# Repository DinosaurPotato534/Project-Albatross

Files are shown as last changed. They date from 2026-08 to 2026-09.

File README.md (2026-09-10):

# Project Albatross

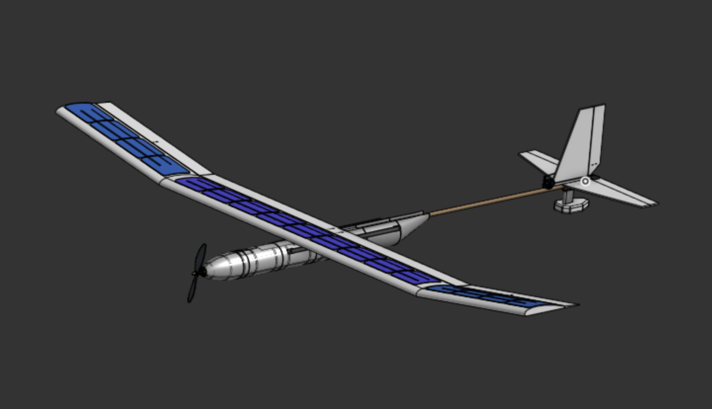
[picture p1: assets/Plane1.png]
plane


The goal for the project was to create an autonomous plane capable of flying for hours off of solar power. Another big aspect is the ability to takeoff from water using a pontoon system mounted to a 4-bar linkage. The plane is going to be made from foam board and 3d prints. The wingspan is 90in and the length is roughly 6ft. 

https://cad.onshape.com/documents/cb4d8119196719dc9005cd1f/w/a50220c0795171ae93763f3d/e/ee41d6fe8c21d3f854f1676d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

## Motivation
We wanted to explore the idea of multi-hour flight using solar power. Most rc planes have a relatively short flight time, but we wanted to try and expand on that. That is why we also added the pontoons, so it could recharge on the surface of water.

## Design

### Pontoons
The pontoon mechanism works by having two hollow 3D printed hulls swing out when landing. The reason we decided to put them on a swinging mechanism was that it would greatly reduce drag, and in turn air resistance. Just based on frontal area that's around a 25% increase in efficiency. They will be driven by a motor that will winch it up or down.
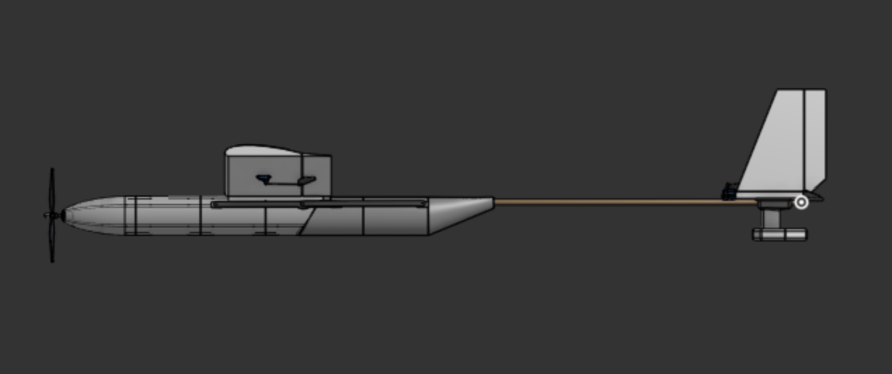
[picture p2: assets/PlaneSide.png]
side

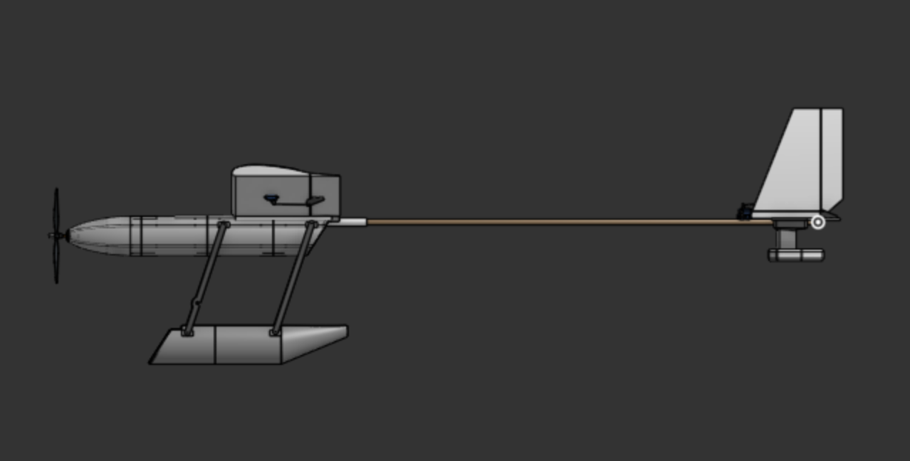
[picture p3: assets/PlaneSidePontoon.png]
side2


### Solar Panels
The solar panels just sit on the wing and will be wired to an MPPT board. They each generate around 3.5W in full sun, and there will be 17. It should be enough to sustain flight, but it will almost never get perfect lighting, so we will see. These sit on a 90in wing that has an 7in chord (not including the ailerons). Panels measure 125mm, so roughly 5in.
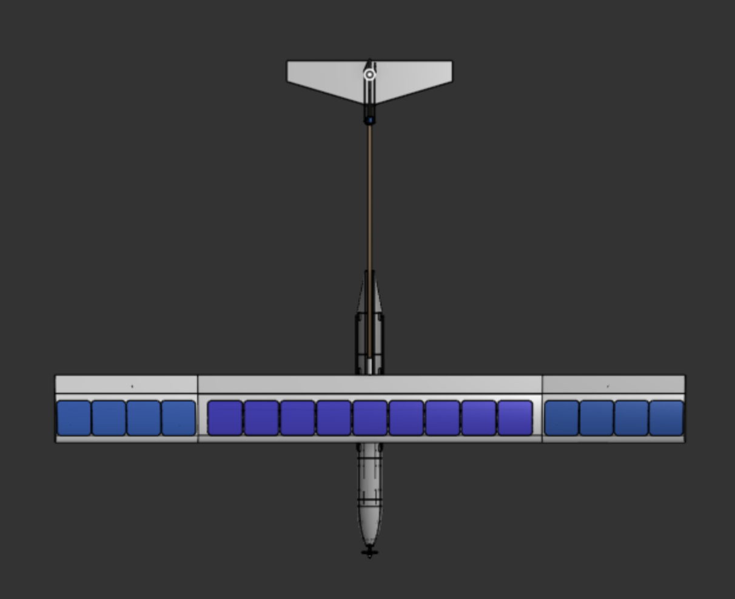
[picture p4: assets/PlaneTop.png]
wings


### Hull
Used a series of ribs inside to support a really thin outer shell of 3D print. These will slide down into their corresponding spots, making the structure much stronger. The front one also serves as the motor mount too.
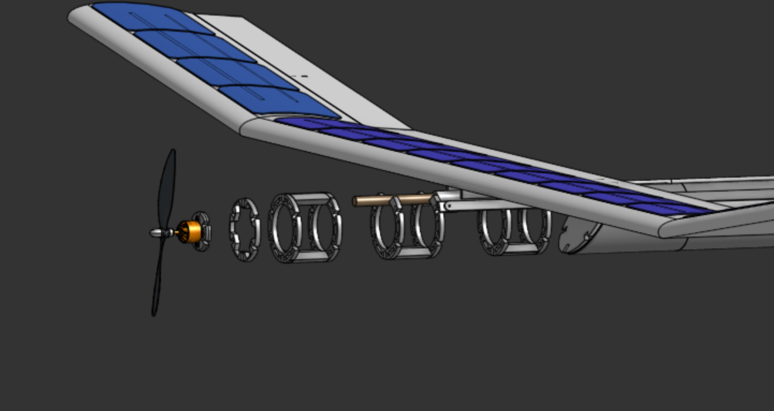
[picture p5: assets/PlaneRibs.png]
ribs


## PCB
### Flight Controller
The flight controller was built with Ardupilot in mind, with multiple connectors allowing for different sensors to be modular and  swapped out. It is designed to take a 3 or 4S battery, and runs on an STM32F405RGT6. We are planning on using a GPS and a magnetometer but we have extra connector for different sensors if we want to add them going forward. We also have an IMU and pressure sensor on the board.
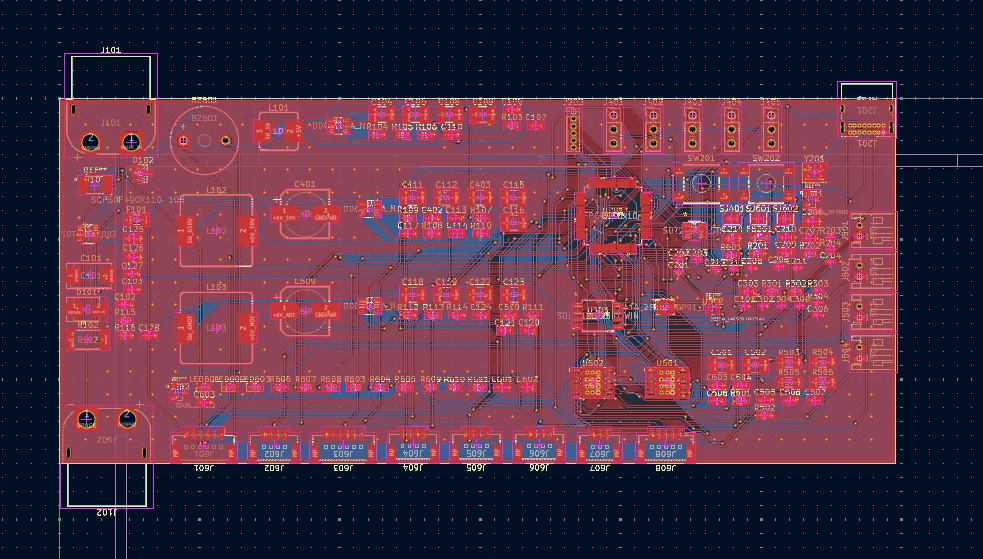
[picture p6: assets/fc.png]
Flight Controller


### MPPT Board
We made a full solar circuit, with a MPPT board and BMI. With this plane design we kept the wings relatively small. Only 17 solar panels could fit. With each solar panel proving roughly 0.6V the total voltage was roughly 10V. This is well below the standard voltage of a 4s battery, thus we needed a step up MPPT board. The market for this is miniscule and expensive leading our design to be useful as it functioned as both a step up and step down board depending on the solar array. However, our board also ended up being far to expensive to become justifiable. We decided to pivot to using a standard step down MPPT and increasing the solar area, as well as deceasing the battery voltage to a 3S.
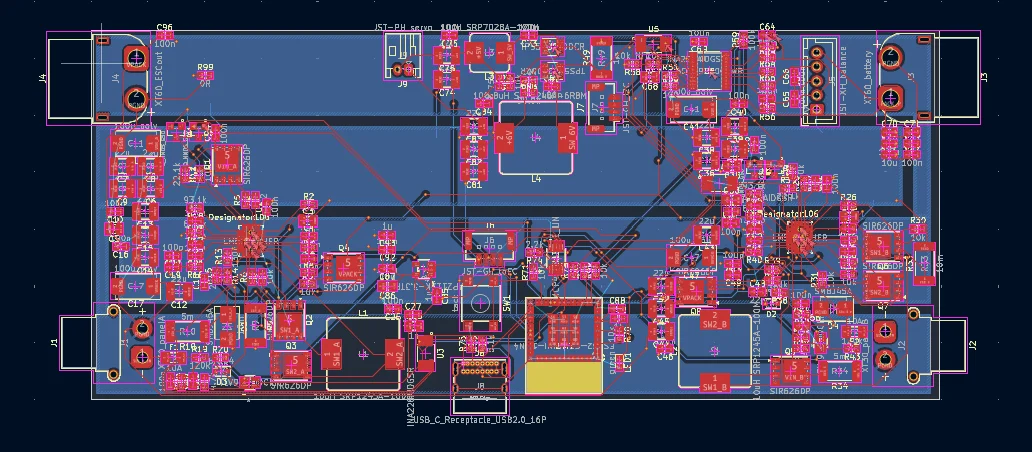
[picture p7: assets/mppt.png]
MPPT Board


## Assembly 

### The Plane
Most of the planes assembly consists of techniques similar to other rc planes. The wings are made from foam board "wrapped" around a dowel spar. They are made by cutting 3 slits across a sheet of foam board spaced out at 7in, 8iin, and 17 from one end. Then the paper layer of the foam board is peeled off for the top of the airfoil to create a better curve. The foam board is folded over the wing spar and three sections of these are connected.

The body is made from a dowel as the main structure of the hull, with 3d printed shells for aerodynamics and part containers. The slide onto the dowel and will be hot glued into place. Then the electronics are wired and placed into the nose cone of the 3d printed hull. The pontoons can then be mounted on they're hinges, which will be connected to n20 motor to swing up and down.
Solar panels will be mounted on the wing using a plastic wrap to hold them in place, while still allowing sunlight through.

### The PCB
Both the pcbs, especially the mppt board, are rather complex and have a lot of smd soldering. The use of a hot plate will be need and following the design the components will be soldered on. These boards will then be wired and hooked up to the rest of the planes electronics.

## BOM

| Description | Quantity | Price | Link |
| --- | ---: | ---: | --- |
| Main Brushless Motor | 0 | 19.98 | [View](https://www.amazon.com/D2830-Brushless-Multi-Copter-Fixed-Wing-Helicopters/dp/B0D3DTQCS6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) |
| Propeller | 0 | 9.19 | [View](https://www.amazon.com/FOCMKEAS-Propeller-Control-Quadcopter-Propellers/dp/B0F7LGSVNX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) |
| Light Weight PLA | 1 | 29.99 | [View](https://www.amazon.com/Polymaker-PolyLite-LW-PLA-1-75mm-800g/dp/B09H2SC1CX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) |
| Solar Panels | 30 | 4 | [View](https://www.ebay.com/itm/382873833299?_trksid=p2332490.c101224.m-1&var=651906635231) |
| Servos (5 Pack) | 1 | 15.99 | [View](https://www.amazon.com/dp/B0BWJ2CK9D?_encoding=UTF8&th=1) |
| Servo Extention Cables | 1 | 9.99 | [View](https://www.amazon.com/ACEIRMC-Extension-Connector-Airplanes-Control/dp/B0CP7FRV31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) |
| 3S Lipo | 0 | 16.99 | [View](https://www.amazon.com/2200mAh-Connector-Airplane-Quadcopter-Helicopter/dp/B08CZF373Y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) |
| ESC | 0 | 28.4 | [View](https://www.amazon.com/60A-Brushless-Fixed-Wing-Aircraft-Helicopter/dp/B0FRM7X984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) |
| Heat Set Inserts | 1 | 4.99 | [View](https://www.amazon.com/Aoserge-100Pcs-Brass-Heat-Inserts/dp/B0FM45X5TD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) |
| M3 Screws | 1 | 6.99 | [View](https://www.amazon.com/Machine-Assorted-Assortment-Stainless-Threaded/dp/B0DFWX8F36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) |
| Controller | 0 | 54.89 | [View](https://www.amazon.com/FLYSKY-Transmitter-Controller-Receiver-Upgrade/dp/B07Z8VCB45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) |
| Foam Board | 10 | 1.25 | [View](https://www.dollartree.com/readi-board-white-foam-boards/809955) |
| N20 Motor | 4 | 4.17 | [View](https://www.aliexpress.us/item/3256803908995996.html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) |
| GPS | 1 | 15.9 | [View](https://robofusion.net/products/mg-a01-gps-module) |
| Telemetry | 1 | 65.9 | [View](https://robofusion.net/products/micoair-lr900-p-915mhz-lora-telemetry-radio-for-pixhawk-ardupilot-px4-1w-fhss-flagship-long-range-pair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) |
| BMS | 1 | 1.13 | [View](https://www.aliexpress.us/item/3256807501448998.html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)  |
| MPPT Board | 1 | 20.41 | [View](https://www.aliexpress.us/item/3256810455381147.html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) |
| passive piezo | 5 | 0.4017 | [View](https://www.lcsc.com/product-detail/C128650.html?s_z=n_q_C128650&globalKeyword=C128650) |
| 100u/35V poly | 50 | 0.0139 | [View](https://www.lcsc.com/product-detail/C14663.html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) |
| 100n/50V 0603 | 10 | 0.2003 | [View](https://www.lcsc.com/product-detail/Multilayer-Ceramic-Capacitors-MLCC-SMD-SMT_Taiyo-Yuden-TMK325BJ106KN-T_C92834.html) |
| 10u/25V 1210 | 10 | 0.2257 | [View](https://www.lcsc.com/product-detail/C92771.html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) |
| 22u/16V 1210 | 20 | 0.0291 | [View](https://www.lcsc.com/product-detail/multilayer-ceramic-capacitors-mlcc-smd-smt_cctc-tcc0805x7r105k250ft_C282734.html) |
| 1u 0805 | 100 | 0.005 | [View](https://www.lcsc.com/product-detail/C60474.html) |
| 100n 0402 | 10 | 0.0614 | [View](https://www.lcsc.com/product-detail/C132176.html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) |
| 4.7u 0805 | 50 | 0.0138 | [View](https://www.lcsc.com/product-detail/Multilayer-Ceramic-Capacitors-MLCC-SMD-SMT_1uF-105-10-16V_C93816.html) |
| 1u 0603 | 50 | 0.0191 | [View](https://www.lcsc.com/product-detail/C23630.html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) |
| 2.2u 0603 | 100 | 0.007 | [View](https://www.lcsc.com/product-detail/C342941.html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) |
| 10p 0402 | 10 | 0.0803 | [View](https://www.lcsc.com/product-detail/C96179.html) |
| 470u/16V 8x10.5 | 5 | 0.2003 | [View](https://www.lcsc.com/product-detail/Multilayer-Ceramic-Capacitors-MLCC-SMD-SMT_Taiyo-Yuden-TMK325BJ106KN-T_C92834.html) |
| 10u 1210 | 5 | 0.1813 | [View](https://www.lcsc.com/product-detail/C318781.html?s_z=n_q_C318781&globalKeyword=C318781) |
| 10u/16V 1210 | 20 | 0.04 | [View](https://www.lcsc.com/product-detail/C386014.html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) |
| 2.2u/6.3V 0603 | 10 | 0.061 | [View](https://www.digikey.com/en/products/detail/kemet/C0603C103K5RACTU/411090) |
| 10n/16V 0603 | 4 | 0.5 | [View](https://www.digikey.com/en/products/detail/littelfuse-inc/SMBJ20A/285988) |
| SMBJ20A | 5 | 0.16 | [View](https://www.digikey.com/en/products/detail/diotec-semiconductor/BAT54C/13163831) |
| BAT54C | 1 | 2.7641 | [View](https://www.lcsc.com/product-detail/C1512043.html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) |
| Fuse 3A 1206 | 10 | 0.0283 | [View](https://www.lcsc.com/product-detail/C21519.html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) |
| 600R@100MHz 0805 | 3 | 0.65 | [View](https://www.lcsc.com/product-detail/C428722.html) |
| USB4085 | 1 | 0.91 | [View](https://www.digikey.com/en/products/detail/gct/USB4085-GF-A/9859662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) |
| Connector_PinHeader_1.27mm:PinHeader_1x06_P1.27mm_Vertical | 5 | 0.2606 | [View](https://www.lcsc.com/product-detail/C3408.html?s_z=n_q_C3408&globalKeyword=C3408) |
| Connector_PinHeader_2.54mm:PinHeader_1x03_P2.54mm_Vertical | 20 | 0.0278 | [View](https://www.lcsc.com/product-detail/C49257.html) |
| Connector_JST:JST_PH_S2B-PH-K_1x02_P2.00mm_Horizontal | 10 | 0.0669 | [View](https://www.lcsc.com/product-detail/C265016.html) |
| Connector_JST:JST_GH_BM06B-GHS-TBT_1x06-1MP_P1.25mm_Vertical | 5 | 0.3036 | [View](https://www.lcsc.com/product-detail/C189892.html) |
| Connector_JST:JST_GH_BM04B-GHS-TBT_1x04-1MP_P1.25mm_Vertical | 10 | 0.1301 | [View](https://www.lcsc.com/product-detail/C3011955.html?s_z=n_q_C3011955&globalKeyword=C3011955) |
| Connector_JST:JST_GH_BM03B-GHS-TBT_1x03-1MP_P1.25mm_Vertical | 5 | 0.2223 | [View](https://www.lcsc.com/product-detail/C161691.html) |
| Connector_JST:JST_GH_BM05B-GHS-TBT_1x05-1MP_P1.25mm_Vertical | 1 | 0.5359 | [View](https://www.lcsc.com/product-detail/C189891.html) |
| 10uH SRP7028A-100M | 1 | 1.1 | [View](https://www.digikey.com/en/products/detail/bourns-inc/SRP7028A-100M/4876641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) |
| 6.8uH SRP1245A-6R8M | 2 | 1.47 | [View](https://www.digikey.com/en/products/detail/bourns-inc/SRP1245A-6R8M/4876614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) |
| red LED_0603 | 2 | 0.14 | [View](https://www.digikey.com/en/products/detail/liteon/LTST-C190KRKT/386817) |
| blue LED_0603 | 2 | 0.16 | [View](https://www.digikey.com/en/products/detail/w%C3%BCrth-elektronik/150060BS75000/4489895) |
| green PWR LED_0603 | 2 | 0.14 | [View](https://www.digikey.com/en/products/detail/liteon/LTST-C190GKT/269230) |
| 2N7002 | 50 | 0.0112 | [View](https://www.lcsc.com/product-detail/C916396.html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) |
| 1m 2512 | 20 | 0.0512 | [View](https://www.lcsc.com/product-detail/C55485.html?s_z=n_q_C55485&globalKeyword=C55485) |
| 63.4k 0603 | 10 | 0.021 | [View](https://www.digikey.com/en/products/detail/stackpole-electronics-inc/RMCF0603FT63K4/1714177) |
| 10k 0603 | 25 | 0.024 | [View](https://www.digikey.com/en/products/detail/vishay-dale/CRCW060310K0FKEA/1174782) |
| 75k 0603 | 10 | 0.028 | [View](https://www.digikey.com/en/products/detail/yageo/AC0603FR-0775KL/5896284) |
| 90.9k 0603 | 10 | 0.021 | [View](https://www.digikey.com/en/products/detail/bourns-inc/CR0603-FX-9092ELF/3784211) |
| 47k 1% 0603 | 10 | 0.025 | [View](https://www.digikey.com/en/products/detail/yageo/RC0603FR-0747KL/727253) |
| 10k 1% 0603 | 10 | 0.032 | [View](https://www.digikey.com/en/products/detail/vishay-dale/CRCW060310K0FKEA/1174782) |
| 5.1k 0402 | 10 | 0.021 | [View](https://www.digikey.com/en/products/detail/yageo/RC0402FR-075K1L/726624) |
| 4.7k 0603 | 10 | 0.025 | [View](https://www.digikey.com/en/products/detail/yageo/RC0603FR-074K7L/727212) |
| 10k 0402 | 10 | 0.02 | [View](https://www.digikey.com/en/products/detail/stackpole-electronics-inc/RMCF0402FT10K0/1761433) |
| 100k 0603 | 10 | 0.025 | [View](https://www.digikey.com/en/products/detail/yageo/RC0603FR-07100KL/726889) |
| 0R15 0.5W 1206 | 10 | 0.299 | [View](https://www.digikey.com/en/products/detail/panasonic-industry/ERJ-8BSFR15V/3982644) |
| 330R 0603 | 10 | 0.025 | [View](https://www.digikey.com/en/products/detail/yageo/RC0603FR-07330RL/727162) |
| 220R 0603 | 10 | 0.025 | [View](https://www.digikey.com/en/products/detail/yageo/RC0603FR-07220RL/727061) |
| 470R 0603 | 10 | 0.02 | [View](https://www.digikey.com/en/products/detail/stackpole-electronics-inc/RMCF0603JT470R/1757954) |
| 1k 0603 | 10 | 0.025 | [View](https://www.digikey.com/en/products/detail/yageo/RC0603FR-071KL/726843) |
| B3S-1000 | 5 | 0.34 | [View](https://www.lcsc.com/product-detail/C2733655.html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) |
| INA228AIDGSR | 1 | 4.68 | [View](https://www.digikey.com/en/products/detail/texas-instruments/INA228AIDGSR/13691042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) |
| TPS54202DDCR | 1 | 1.53 | [View](https://www.digikey.com/en/products/detail/texas-instruments/TPS54202DDCR/6005348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) |
| TPS54302DDCR | 2 | 1.41 | [View](https://www.digikey.com/en/products/detail/texas-instruments/TPS54302DDCR/6572466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) |
| AP2112K-3.3TRG1 | 2 | 0.28 | [View](https://www.digikey.com/en/products/detail/diodes-incorporated/AP2112K-3-3TRG1/4470746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) |
| STM32F405RGT6 | 1 | 6.47 | [View](https://www.lcsc.com/product-detail/C15742.html) |
| USBLC6-2SC6 | 2 | 0.54 | [View](https://www.digikey.com/en/products/detail/stmicroelectronics/USBLC6-2SC6/1040559) |
| ICM-42688-P | 1 | 4.91 | [View](https://www.digikey.com/en/products/detail/tdk-invensense/ICM-42688-P/10824934) |
| C50506 | 1 | 2.4967 | [View](https://www.lcsc.com/product-detail/C50506.html?s_z=n_q_C50506&globalKeyword=C50506) |
| W25Q128JVSIQ | 1 | 2.62 | [View](https://www.lcsc.com/product-detail/C97521.html) |
| DRV8833PWP | 2 | 2.5 | [View](https://www.lcsc.com/product-detail/C50506.html) |
| 8.000MHz 10ppm CL8pF | 2 | 0.73 | [View](https://www.digikey.com/en/products/detail/ndk-nihon-dempa-kogyo-co-ltd/CG04874-8M/9172047) |
| PCB | 1 | 8.4 | [View](JLCPCB) |
| | | | |
| Shipping | | | |
| Amazon | 1 | 0 | |
| JLCPCB | 1 | 8.4132 | |
| Aliexpress | 1 | 0 | |
| Digikey | 1 | 16.67 | |
| LCSC | 1 | 11.81 | |
| Ebay(Tax) | 1 | 7.66 | |
| RoboFusion | 1 | 5.9 | |
| | | | |
| Total | | 458.7009 | |

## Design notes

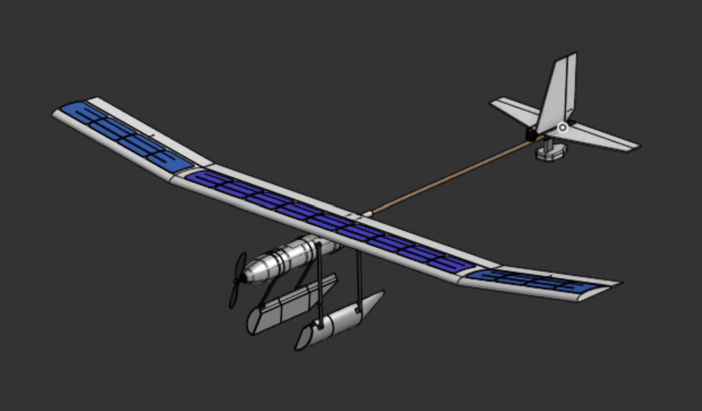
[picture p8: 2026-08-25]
assets/PlanePontoon1.png

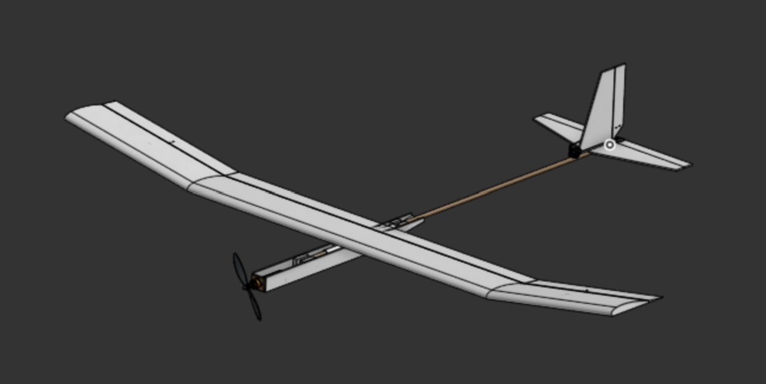
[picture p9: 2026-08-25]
assets/FoamboardCAD.png

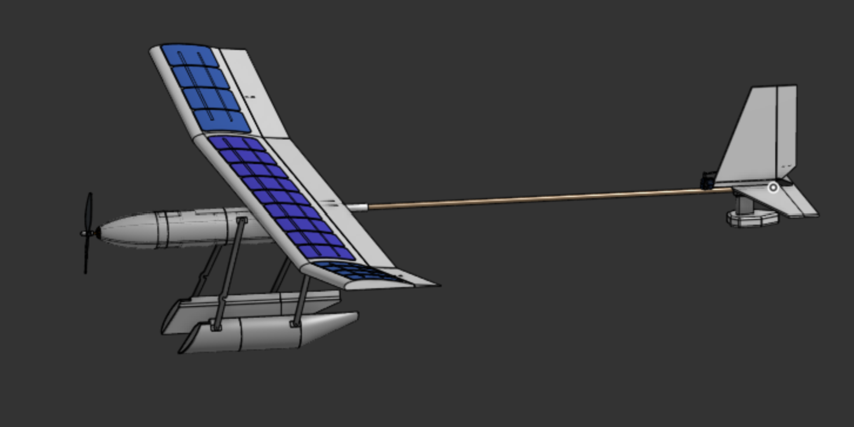
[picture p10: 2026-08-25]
assets/PlanePontoon2.png

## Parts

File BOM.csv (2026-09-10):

Description | Quanity | Price | Link
Main Brushless Motor | 0 | 19.98 | https://www.amazon.com/D2830-Brushless-Multi-Copter-Fixed-Wing-Helicopters/dp/B0D3DTQCS6?s=industrial
Propeller | 0 | 9.19 | https://www.amazon.com/FOCMKEAS-Propeller-Control-Quadcopter-Propellers/dp/B0F7LGSVNX
Light Weight PLA | 1 | 29.99 | https://www.amazon.com/Polymaker-PolyLite-LW-PLA-1-75mm-800g/dp/B09H2SC1CX
Solar Panels | 30 | 4 | https://www.ebay.com/itm/382873833299?_trksid=p2332490.c101224.m-1&var=651906635231
Servos (5 Pack) | 1 | 15.99 | https://www.amazon.com/dp/B0BWJ2CK9D?_encoding=UTF8&th=1
Servo Extention Cables | 1 | 9.99 | https://www.amazon.com/ACEIRMC-Extension-Connector-Airplanes-Control/dp/B0CP7FRV31
3S Lipo | 0 | 16.99 | https://www.amazon.com/2200mAh-Connector-Airplane-Quadcopter-Helicopter/dp/B08CZF373Y
ESC | 0 | 28.4 | https://www.amazon.com/60A-Brushless-Fixed-Wing-Aircraft-Helicopter/dp/B0FRM7X984
Heat Set Inserts | 1 | 4.99 | https://www.amazon.com/Aoserge-100Pcs-Brass-Heat-Inserts/dp/B0FM45X5TD?rnid=386419011
M3 Screws | 1 | 6.99 | https://www.amazon.com/Machine-Assorted-Assortment-Stainless-Threaded/dp/B0DFWX8F36?rnid=2661611011
Controller | 0 | 54.89 | https://www.amazon.com/FLYSKY-Transmitter-Controller-Receiver-Upgrade/dp/B07Z8VCB45
Foam Board | 10 | 1.25 | https://www.dollartree.com/readi-board-white-foam-boards/809955
N20 Motor | 4 | 4.17 | https://www.aliexpress.us/item/3256803908995996.html?curPageLogUid=oM71zmsPOiT8
GPS | 1 | 15.9 | https://robofusion.net/products/mg-a01-gps-module
Telemetry | 1 | 65.9 | https://robofusion.net/products/micoair-lr900-p-915mhz-lora-telemetry-radio-for-pixhawk-ardupilot-px4-1w-fhss-flagship-long-range-pair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
BMS | 1 | 1.13 | https://www.aliexpress.us/item/3256807501448998.html?curPageLogUid=EdmXCWhx64s9
MPPT Board | 1 | 20.41 | https://www.aliexpress.us/item/3256810455381147.html?curPageLogUid=7y9B1Ewqa6k0
passive piezo | 5 | 0.4017 | https://www.lcsc.com/product-detail/C128650.html?s_z=n_q_C128650&globalKeyword=C128650
100u/35V poly | 50 | 0.0139 | https://www.lcsc.com/product-detail/C14663.html?s_z=n_q_CC0603KRX7R9BB104
100n/50V 0603 | 10 | 0.2003 | https://www.lcsc.com/product-detail/Multilayer-Ceramic-Capacitors-MLCC-SMD-SMT_Taiyo-Yuden-TMK325BJ106KN-T_C92834.html
10u/25V 1210 | 10 | 0.2257 | https://www.lcsc.com/product-detail/C92771.html?s_z=n_q_Taiyo%2520Yuden%2520EMK325BJ226MD-T
22u/16V 1210 | 20 | 0.0291 | https://www.lcsc.com/product-detail/multilayer-ceramic-capacitors-mlcc-smd-smt_cctc-tcc0805x7r105k250ft_C282734.html
1u 0805 | 100 | 0.005 | https://www.lcsc.com/product-detail/C60474.html
100n 0402 | 10 | 0.0614 | https://www.lcsc.com/product-detail/C132176.html?s_z=n_q_CC0805KKX5R7BB475
4.7u 0805 | 50 | 0.0138 | https://www.lcsc.com/product-detail/Multilayer-Ceramic-Capacitors-MLCC-SMD-SMT_1uF-105-10-16V_C93816.html
1u 0603 | 50 | 0.0191 | https://www.lcsc.com/product-detail/C23630.html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
2.2u 0603 | 100 | 0.007 | https://www.lcsc.com/product-detail/C342941.html?s_z=n_q_CGA2B2C0G1H100DT0Y0F
10p 0402 | 10 | 0.0803 | https://www.lcsc.com/product-detail/C96179.html
470u/16V 8x10.5 | 5 | 0.2003 | https://www.lcsc.com/product-detail/Multilayer-Ceramic-Capacitors-MLCC-SMD-SMT_Taiyo-Yuden-TMK325BJ106KN-T_C92834.html
10u 1210 | 5 | 0.1813 | https://www.lcsc.com/product-detail/C318781.html?s_z=n_q_C318781&globalKeyword=C318781
10u/16V 1210 | 20 | 0.04 | https://www.lcsc.com/product-detail/C386014.html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
2.2u/6.3V 0603 | 10 | 0.061 | https://www.digikey.com/en/products/detail/kemet/C0603C103K5RACTU/411090
10n/16V 0603 | 4 | 0.5 | https://www.digikey.com/en/products/detail/littelfuse-inc/SMBJ20A/285988
SMBJ20A | 5 | 0.16 | https://www.digikey.com/en/products/detail/diotec-semiconductor/BAT54C/13163831
BAT54C | 1 | 2.7641 | https://www.lcsc.com/product-detail/C1512043.html?s_z=n_q_1206L300%252F12SLYR
Fuse 3A 1206 | 10 | 0.0283 | https://www.lcsc.com/product-detail/C21519.html?s_z=n_q_MPZ2012S601AT000
600R@100MHz 0805 | 3 | 0.65 | https://www.lcsc.com/product-detail/C428722.html
USB4085 | 1 | 0.91 | https://www.digikey.com/en/products/detail/gct/USB4085-GF-A/9859662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
Connector_PinHeader_1.27mm:PinHeader_1x06_P1.27mm_Vertical | 5 | 0.2606 | https://www.lcsc.com/product-detail/C3408.html?s_z=n_q_C3408&globalKeyword=C3408
Connector_PinHeader_2.54mm:PinHeader_1x03_P2.54mm_Vertical | 20 | 0.0278 | https://www.lcsc.com/product-detail/C49257.html
Connector_JST:JST_PH_S2B-PH-K_1x02_P2.00mm_Horizontal | 10 | 0.0669 | https://www.lcsc.com/product-detail/C265016.html
Connector_JST:JST_GH_BM06B-GHS-TBT_1x06-1MP_P1.25mm_Vertical | 5 | 0.3036 | https://www.lcsc.com/product-detail/C189892.html
Connector_JST:JST_GH_BM04B-GHS-TBT_1x04-1MP_P1.25mm_Vertical | 10 | 0.1301 | https://www.lcsc.com/product-detail/C3011955.html?s_z=n_q_C3011955&globalKeyword=C3011955
Connector_JST:JST_GH_BM03B-GHS-TBT_1x03-1MP_P1.25mm_Vertical | 5 | 0.2223 | https://www.lcsc.com/product-detail/C161691.html
Connector_JST:JST_GH_BM05B-GHS-TBT_1x05-1MP_P1.25mm_Vertical | 1 | 0.5359 | https://www.lcsc.com/product-detail/C189891.html
10uH SRP7028A-100M | 1 | 1.1 | https://www.digikey.com/en/products/detail/bourns-inc/SRP7028A-100M/4876641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
6.8uH SRP1245A-6R8M | 2 | 1.47 | https://www.digikey.com/en/products/detail/bourns-inc/SRP1245A-6R8M/4876614
red LED_0603 | 2 | 0.14 | https://www.digikey.com/en/products/detail/liteon/LTST-C190KRKT/386817
blue LED_0603 | 2 | 0.16 | https://www.digikey.com/en/products/detail/w%C3%BCrth-elektronik/150060BS75000/4489895
green PWR LED_0603 | 2 | 0.14 | https://www.digikey.com/en/products/detail/liteon/LTST-C190GKT/269230
2N7002 | 50 | 0.0112 | https://www.lcsc.com/product-detail/C916396.html?s_z=n_q_x_2N7002
1m 2512 | 20 | 0.0512 | https://www.lcsc.com/product-detail/C55485.html?s_z=n_q_C55485&globalKeyword=C55485
63.4k 0603 | 10 | 0.021 | https://www.digikey.com/en/products/detail/stackpole-electronics-inc/RMCF0603FT63K4/1714177
10k 0603 | 25 | 0.024 | https://www.digikey.com/en/products/detail/vishay-dale/CRCW060310K0FKEA/1174782
75k 0603 | 10 | 0.028 | https://www.digikey.com/en/products/detail/yageo/AC0603FR-0775KL/5896284
90.9k 0603 | 10 | 0.021 | https://www.digikey.com/en/products/detail/bourns-inc/CR0603-FX-9092ELF/3784211
47k 1% 0603 | 10 | 0.025 | https://www.digikey.com/en/products/detail/yageo/RC0603FR-0747KL/727253
10k 1% 0603 | 10 | 0.032 | https://www.digikey.com/en/products/detail/vishay-dale/CRCW060310K0FKEA/1174782
5.1k 0402 | 10 | 0.021 | https://www.digikey.com/en/products/detail/yageo/RC0402FR-075K1L/726624
4.7k 0603 | 10 | 0.025 | https://www.digikey.com/en/products/detail/yageo/RC0603FR-074K7L/727212
10k 0402 | 10 | 0.02 | https://www.digikey.com/en/products/detail/stackpole-electronics-inc/RMCF0402FT10K0/1761433
100k 0603 | 10 | 0.025 | https://www.digikey.com/en/products/detail/yageo/RC0603FR-07100KL/726889
0R15 0.5W 1206 | 10 | 0.299 | https://www.digikey.com/en/products/detail/panasonic-industry/ERJ-8BSFR15V/3982644
330R 0603 | 10 | 0.025 | https://www.digikey.com/en/products/detail/yageo/RC0603FR-07330RL/727162
220R 0603 | 10 | 0.025 | https://www.digikey.com/en/products/detail/yageo/RC0603FR-07220RL/727061
470R 0603 | 10 | 0.02 | https://www.digikey.com/en/products/detail/stackpole-electronics-inc/RMCF0603JT470R/1757954
1k 0603 | 10 | 0.025 | https://www.digikey.com/en/products/detail/yageo/RC0603FR-071KL/726843
B3S-1000 | 5 | 0.34 | https://www.lcsc.com/product-detail/C2733655.html?s_z=n_q_B3S-1000
INA228AIDGSR | 1 | 4.68 | https://www.digikey.com/en/products/detail/texas-instruments/INA228AIDGSR/13691042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
TPS54202DDCR | 1 | 1.53 | https://www.digikey.com/en/products/detail/texas-instruments/TPS54202DDCR/6005348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
TPS54302DDCR | 2 | 1.41 | https://www.digikey.com/en/products/detail/texas-instruments/TPS54302DDCR/6572466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
AP2112K-3.3TRG1 | 2 | 0.28 | https://www.digikey.com/en/products/detail/diodes-incorporated/AP2112K-3-3TRG1/4470746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
STM32F405RGT6 | 1 | 6.47 | https://www.lcsc.com/product-detail/C15742.html
USBLC6-2SC6 | 2 | 0.54 | https://www.digikey.com/en/products/detail/stmicroelectronics/USBLC6-2SC6/1040559
ICM-42688-P | 1 | 4.91 | https://www.digikey.com/en/products/detail/tdk-invensense/ICM-42688-P/10824934
C50506 | 1 | 2.4967 | https://www.lcsc.com/product-detail/C50506.html?s_z=n_q_C50506&globalKeyword=C50506
W25Q128JVSIQ | 1 | 2.62 | https://www.lcsc.com/product-detail/C97521.html
DRV8833PWP | 2 | 2.5 | https://www.lcsc.com/product-detail/C50506.html
8.000MHz 10ppm CL8pF | 2 | 0.73 | https://www.digikey.com/en/products/detail/ndk-nihon-dempa-kogyo-co-ltd/CG04874-8M/9172047
PCB | 1 | 8.4 | JLCPCB
Shipping
Amazon | 1 | 0
JLCPCB | 1 | 8.4132
Aliexpress | 1 | 0
Digikey | 1 | 16.67
LCSC | 1 | 11.81
Ebay(Tax) | 1 | 7.66
RoboFusion | 1 | 5.9
Total |  | 458.7009

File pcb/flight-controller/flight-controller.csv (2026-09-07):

Reference | Qty | Value | DNP | Exclude from BOM | Exclude from Board | Footprint | Datasheet
BZ601 | 1 | passive piezo |  |  |  | Buzzer_Beeper:Buzzer_12x9.5RM7.6
C101 | 1 | 100u/35V poly |  |  |  | Capacitor_Tantalum_SMD:CP_EIA-7343-31_Kemet-D
C102,C106,C113,C120 | 4 | 100n/50V |  |  |  | Capacitor_SMD:C_0603_1608Metric
C103,C107,C110,C114,C117,C121,C124,C127,C128,C402,C503,C504,C510,C601,C602,C603 | 16 | 100n |  |  |  | Capacitor_SMD:C_0603_1608Metric
C104,C105,C111,C112,C118,C119 | 6 | 10u/25V |  |  |  | Capacitor_SMD:C_1210_3225Metric
C108,C109,C115,C116,C122,C123 | 6 | 22u/16V |  |  |  | Capacitor_SMD:C_1210_3225Metric
C125,C126 | 2 | 1u |  |  |  | Capacitor_SMD:C_0805_2012Metric
C201,C202,C203,C204,C205,C208,C213,C301,C302,C304,C305,C306 | 12 | 100n |  |  |  | Capacitor_SMD:C_0402_1005Metric
C206,C214 | 2 | 4.7u |  |  |  | Capacitor_SMD:C_0805_2012Metric
C207 | 1 | 1u |  |  |  | Capacitor_SMD:C_0603_1608Metric
C209,C210,C303 | 3 | 2.2u |  |  |  | Capacitor_SMD:C_0603_1608Metric
C211,C212 | 2 | 10p |  |  |  | Capacitor_SMD:C_0402_1005Metric
C401,C509 | 2 | 470u/16V |  |  |  | Capacitor_SMD:CP_Elec_8x10.5
C403 | 1 | 10u |  |  |  | Capacitor_SMD:C_1210_3225Metric
C501,C502 | 2 | 10u/16V |  |  |  | Capacitor_SMD:C_1210_3225Metric
C505,C506 | 2 | 2.2u/6.3V |  |  |  | Capacitor_SMD:C_0603_1608Metric
C507,C508 | 2 | 10n/16V |  |  |  | Capacitor_SMD:C_0603_1608Metric
D101 | 1 | SMBJ20A |  |  |  | Diode_SMD:D_SMB
D102 | 1 | BAT54C |  |  |  | Package_TO_SOT_SMD:SOT-23
F101 | 1 | 3A |  |  |  | Fuse:Fuse_1206_3216Metric
FB201 | 1 | 600R@100MHz |  |  |  | Inductor_SMD:L_0805_2012Metric
J101 | 1 | XT60_PACK_IN |  |  |  | Connector_AMASS:AMASS_XT60PW-F_1x02_P7.20mm_Horizontal
J102 | 1 | XT60_ESC_OUT |  |  |  | Connector_AMASS:AMASS_XT60PW-F_1x02_P7.20mm_Horizontal
J201 | 1 | USB-C |  |  |  | Connector_USB:USB_C_Receptacle_GCT_USB4085
J202 | 1 | SWD+SWO |  |  |  | Connector_PinHeader_1.27mm:PinHeader_1x06_P1.27mm_Vertical
J401 | 1 | ESC_SIGNAL |  |  |  | Connector_PinHeader_2.54mm:PinHeader_1x03_P2.54mm_Vertical
J402 | 1 | SERVO1_AIL_L |  |  |  | Connector_PinHeader_2.54mm:PinHeader_1x03_P2.54mm_Vertical
J403 | 1 | SERVO2_AIL_R |  |  |  | Connector_PinHeader_2.54mm:PinHeader_1x03_P2.54mm_Vertical
J404 | 1 | SERVO3_ELEVATOR |  |  |  | Connector_PinHeader_2.54mm:PinHeader_1x03_P2.54mm_Vertical
J405 | 1 | SERVO4_RUDDER |  |  |  | Connector_PinHeader_2.54mm:PinHeader_1x03_P2.54mm_Vertical
J501 | 1 | N20_1 |  |  |  | Connector_JST:JST_PH_S2B-PH-K_1x02_P2.00mm_Horizontal
J502 | 1 | N20_2 |  |  |  | Connector_JST:JST_PH_S2B-PH-K_1x02_P2.00mm_Horizontal
J503 | 1 | N20_3 |  |  |  | Connector_JST:JST_PH_S2B-PH-K_1x02_P2.00mm_Horizontal
J504 | 1 | N20_4 |  |  |  | Connector_JST:JST_PH_S2B-PH-K_1x02_P2.00mm_Horizontal
J601 | 1 | GPS_COMPASS |  |  |  | Connector_JST:JST_GH_BM06B-GHS-TBT_1x06-1MP_P1.25mm_Vertical
J602 | 1 | RC_IN_CRSF_SBUS |  |  |  | Connector_JST:JST_GH_BM04B-GHS-TBT_1x04-1MP_P1.25mm_Vertical
J603 | 1 | TELEM1_MAVLINK |  |  |  | Connector_JST:JST_GH_BM06B-GHS-TBT_1x06-1MP_P1.25mm_Vertical
J604 | 1 | SOLAR_BOARD_J6 |  |  |  | Connector_JST:JST_GH_BM04B-GHS-TBT_1x04-1MP_P1.25mm_Vertical
J605 | 1 | I2C_AIRSPEED |  |  |  | Connector_JST:JST_GH_BM04B-GHS-TBT_1x04-1MP_P1.25mm_Vertical
J606 | 1 | UART5_SPARE |  |  |  | Connector_JST:JST_GH_BM04B-GHS-TBT_1x04-1MP_P1.25mm_Vertical
J607 | 1 | SAFETY_SWITCH |  |  |  | Connector_JST:JST_GH_BM03B-GHS-TBT_1x03-1MP_P1.25mm_Vertical
J608 | 1 | ANALOG_IN |  |  |  | Connector_JST:JST_GH_BM05B-GHS-TBT_1x05-1MP_P1.25mm_Vertical
L101 | 1 | 10uH SRP7028A-100M |  |  |  | Inductor_SMD:L_Bourns_SRP7028A_7.3x6.6mm
L102,L103 | 2 | 6.8uH SRP1245A-6R8M |  |  |  | Inductor_SMD:L_Bourns_SRP1245A
LED601 | 1 | red |  |  |  | LED_SMD:LED_0603_1608Metric
LED602 | 1 | blue |  |  |  | LED_SMD:LED_0603_1608Metric
LED603 | 1 | green PWR |  |  |  | LED_SMD:LED_0603_1608Metric
Q601,Q602 | 2 | 2N7002 |  |  |  | 2N7002:TRANS_2N7002
R102 | 1 | 1m |  |  |  | Resistor_SMD:R_2512_6332Metric
R103,R107,R111 | 3 | 63.4k |  |  |  | Resistor_SMD:R_0603_1608Metric
R104,R106,R108,R110,R112,R114,R201,R202,R501,R601,R603,R605 | 12 | 10k |  |  |  | Resistor_SMD:R_0603_1608Metric
R105 | 1 | 75k |  |  |  | Resistor_SMD:R_0603_1608Metric
R109,R113 | 2 | 90.9k |  |  |  | Resistor_SMD:R_0603_1608Metric
R115 | 1 | 47k 1% |  |  |  | Resistor_SMD:R_0603_1608Metric
R116 | 1 | 10k 1% |  |  |  | Resistor_SMD:R_0603_1608Metric
R203,R204 | 2 | 5.1k |  |  |  | Resistor_SMD:R_0402_1005Metric
R301,R302 | 2 | 4.7k |  |  |  | Resistor_SMD:R_0603_1608Metric
R303,R304 | 2 | 10k |  |  |  | Resistor_SMD:R_0402_1005Metric
R502 | 1 | 100k |  |  |  | Resistor_SMD:R_0603_1608Metric
R503,R504,R505,R506 | 4 | 0R15 0.5W |  |  |  | Resistor_SMD:R_1206_3216Metric
R604,R606 | 2 | 330R |  |  |  | Resistor_SMD:R_0603_1608Metric
R607 | 1 | 220R |  |  |  | Resistor_SMD:R_0603_1608Metric
R608 | 1 | 470R |  |  |  | Resistor_SMD:R_0603_1608Metric
R609,R610,R611 | 3 | 1k |  |  |  | Resistor_SMD:R_0603_1608Metric
SJ401 | 1 | ESC_5V_EN |  |  |  | Jumper:SolderJumper-2_P1.3mm_Open_Pad1.0x1.5mm
SJ601 | 1 | CRSF_DIRECT |  |  |  | Jumper:SolderJumper-2_P1.3mm_Bridged_Pad1.0x1.5mm
SJ602 | 1 | SBUS_INVERTED |  |  |  | Jumper:SolderJumper-2_P1.3mm_Open_Pad1.0x1.5mm
SW201 | 1 | RESET |  |  |  | Button_Switch_SMD:SW_SPST_B3S-1000
SW202 | 1 | BOOT0/DFU |  |  |  | Button_Switch_SMD:SW_SPST_B3S-1000
U101 | 1 | INA228AIDGSR |  |  |  | INA228AIDGSR:SOP50P490X110-10N
U102 | 1 | TPS54202DDCR |  |  |  | TPS54202DDCR:DDC0006A_N
U103,U104 | 2 | TPS54302DDCR |  |  |  | TPS54202DDCR:DDC0006A_N
U105 | 1 | AP2112K-3.3TRG1 |  |  |  | AP2112K_3_3TRG1:SOT_RG1_DIO
U201 | 1 | STM32F405RGT6 |  |  |  | STM32F405RGT6:LQFP64-10x10mm
U202 | 1 | USBLC6-2SC6 |  |  |  | USBLC6_2SC6:SOT23-6L_STM
U301 | 1 | ICM-42688-P |  |  |  | ICM_42688_P:LGA14_2P5X3X0P91_TDK
U302 | 1 | DPS310XTSA1 |  |  |  | DPS310XTSA1:XDCR_DPS310XTSA1
U303 | 1 | W25Q128JVSIQ |  |  |  | W25Q128JVSIQ:SOIC_128JVSIQ_WIN
U501,U502 | 2 | DRV8833PWP |  |  |  | Package_SO:HTSSOP-16-1EP_4.4x5mm_P0.65mm_EP3.4x5mm_Mask2.46x2.31mm_ThermalVias
Y201 | 1 | 8.000MHz 10ppm CL8pF |  |  |  | Crystal:Crystal_SMD_3225-4Pin_3.2x2.5mm

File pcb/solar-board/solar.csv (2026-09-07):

Reference | Qty | Value | DNP | Exclude from BOM | Exclude from Board | Footprint | Datasheet
C1,C2,C4,C10,C16,C21,C23,C24,C25,C27,C31,C32,C34,C40,C46,C51,C53,C54,C55,C57,C64,C65,C66,C67,C69,C72,C73,C76,C79,C80,C84,C87,C92,C94,C95,C96 | 36 | 100n |  |  |  | Capacitor_SMD:C_0603_1608Metric
C3,C33,C86 | 3 | 10u |  |  |  | Capacitor_SMD:C_0805_2012Metric
C5,C28,C35,C58,C68 | 5 | 1u |  |  |  | Capacitor_SMD:C_0805_2012Metric
C6,C7,C8,C9,C12,C13,C14,C15,C36,C37,C38,C39,C42,C43,C44,C45,C74,C75,C81,C82,C83 | 21 | 22u |  |  |  | Capacitor_SMD:C_1210_3225Metric
C11,C17,C41,C47 | 4 | 100u_poly |  |  |  | Capacitor_Tantalum_SMD:CP_EIA-7343-31_Kemet-D
C18,C48 | 2 | 22p |  |  |  | Capacitor_SMD:C_0603_1608Metric
C19,C49 | 2 | 4.7n |  |  |  | Capacitor_SMD:C_0603_1608Metric
C20,C50 | 2 | 100p |  |  |  | Capacitor_SMD:C_0603_1608Metric
C22,C52 | 2 | 390p |  |  |  | Capacitor_SMD:C_0603_1608Metric
C26,C56 | 2 | 22n |  |  |  | Capacitor_SMD:C_0603_1608Metric
C70,C71,C77,C78 | 4 | 10u |  |  |  | Capacitor_SMD:C_0603_1608Metric
C85,C88,C93 | 3 | 1u |  |  |  | Capacitor_SMD:C_0603_1608Metric
D1,D4 | 2 | SMBJ45A |  |  |  | Diode_SMD:D_SMB
D2,D3 | 2 | BAT54 |  |  |  | Diode_SMD:D_SOD-323
F1,F2 | 2 | 10A |  |  |  | Fuse:Fuse_1206_3216Metric
J1 | 1 | XT30_panelA |  |  |  | Connector_AMASS:AMASS_XT30PW-F_1x02_P2.50mm_Horizontal
J2 | 1 | XT30_panelB |  |  |  | Connector_AMASS:AMASS_XT30PW-F_1x02_P2.50mm_Horizontal
J3 | 1 | XT60_battery |  |  |  | Connector_AMASS:AMASS_XT60PW-F_1x02_P7.20mm_Horizontal
J4 | 1 | XT60_ESCout |  |  |  | Connector_AMASS:AMASS_XT60PW-F_1x02_P7.20mm_Horizontal
J5 | 1 | JST-XH_balance |  |  |  | Connector_JST:JST_XH_B5B-XH-A_1x05_P2.50mm_Vertical
J6 | 1 | JST-GH_toFC |  |  |  | Connector_JST:JST_GH_BM04B-GHS-TBT_1x04-1MP_P1.25mm_Vertical
J7 | 1 | JST-GH_I2C |  |  |  | Connector_JST:JST_GH_BM04B-GHS-TBT_1x04-1MP_P1.25mm_Vertical
J8 | 1 | USB_C_Receptacle_USB2.0_16P |  |  |  | Connector_USB:USB_C_Receptacle_GCT_USB4085
J9 | 1 | JST-PH_servo |  |  |  | Connector_JST:JST_PH_S2B-PH-K_1x02_P2.00mm_Horizontal
L1,L2 | 2 | 10uH SRP1245A-100M |  |  |  | Inductor_SMD:L_Bourns_SRP1245A
L3 | 1 | 10uH SRP7028A-100M |  |  |  | Inductor_SMD:L_Bourns_SRP7028A_7.3x6.6mm
L4 | 1 | 6.8uH SRP1245A-6R8M |  |  |  | Inductor_SMD:L_Bourns_SRP1245A
LED1 | 1 | green |  |  |  | LED_SMD:LED_0603_1608Metric
Q1,Q2,Q3,Q4,Q5,Q6,Q7,Q8 | 8 | SIR626DP |  |  |  | Package_SO:PowerPAK_SO-8_Single
Q9,Q10,Q11,Q12 | 4 | Q_NMOS_GSD |  |  |  | 2N7002:TRANS_2N7002
R1,R2,R3,R4,R25,R26,R27,R28 | 8 | 2.2 |  |  |  | Resistor_SMD:R_0603_1608Metric
R5,R6,R7,R8,R12,R14,R16,R20,R29,R30,R31,R32,R36,R38,R40,R44,R57,R60,R61,R65,R69,R70,R71 | 23 | 10k |  |  |  | Resistor_SMD:R_0603_1608Metric
R9,R33 | 2 | 10m |  |  |  | Resistor_SMD:R_2512_6332Metric
R10,R34 | 2 | 5m |  |  |  | Resistor_SMD:R_2512_6332Metric
R11,R35 | 2 | 22.1k |  |  |  | Resistor_SMD:R_0603_1608Metric
R13,R37 | 2 | 130k |  |  |  | Resistor_SMD:R_0603_1608Metric
R15,R39 | 2 | 33k |  |  |  | Resistor_SMD:R_0603_1608Metric
R17,R41 | 2 | 84.5k |  |  |  | Resistor_SMD:R_0603_1608Metric
R18,R42 | 2 | 93.1k |  |  |  | Resistor_SMD:R_0603_1608Metric
R19,R43 | 2 | 120k |  |  |  | Resistor_SMD:R_0603_1608Metric
R21,R45 | 2 | 1M |  |  |  | Resistor_SMD:R_0603_1608Metric
R22,R46 | 2 | 4.7k |  |  |  | Resistor_SMD:R_0603_1608Metric
R49 | 1 | 1m |  |  |  | Resistor_SMD:R_2512_6332Metric
R50,R51,R52,R53,R54,R55,R56 | 7 | 100 |  |  |  | Resistor_SMD:R_0603_1608Metric
R58 | 1 | 10k_NTC |  |  |  | Resistor_SMD:R_0603_1608Metric
R59 | 1 | 100k |  |  |  | Resistor_SMD:R_0603_1608Metric
R64 | 1 | 75k |  |  |  | Resistor_SMD:R_0603_1608Metric
R68 | 1 | 90.9k |  |  |  | Resistor_SMD:R_0603_1608Metric
R72 | 1 | 1k |  |  |  | Resistor_SMD:R_0603_1608Metric
R73,R74 | 2 | 2.2k |  |  |  | Resistor_SMD:R_0603_1608Metric
R75,R76 | 2 | 5.1k |  |  |  | Resistor_SMD:R_0603_1608Metric
R99 | 1 | 0R |  |  |  | Resistor_SMD:R_0603_1608Metric
SW1 | 1 | tact |  |  |  | Button_Switch_SMD:SW_SPST_B3S-1000
U1,U2 | 2 | LM5175RHFR |  |  |  | LM5175RHFR:RHF0028A
U3,U4,U5 | 3 | INA228AIDGSR |  |  |  | INA228AIDGSR:SOP50P490X110-10N
U6 | 1 | BQ7692000PWR |  |  |  | BQ7692000PWR:PW0020A_N
U7,U8 | 2 | TLV9061IDCKR |  |  |  | TLV9061IDCKR:DCK5_TEX
U9 | 1 | TPS54202DDCR |  |  |  | TPS54202DDCR:DDC0006A_N
U10 | 1 | TPS54302DDCR |  |  |  | TPS54202DDCR:DDC0006A_N
U11 | 1 | AP2112K-3.3TRG1 |  |  |  | AP2112K_3_3TRG1:SOT_RG1_DIO
U12 | 1 | ESP32-C3-MINI-1-N4 |  |  |  | ESP32_C3_MINI_1_N4:ESP32-C3-MINI-1_EXP
U13 | 1 | MCP4728A0T-E_UN |  |  |  | MCP4728A0T_E_UN:MSOP10_MC_MCH

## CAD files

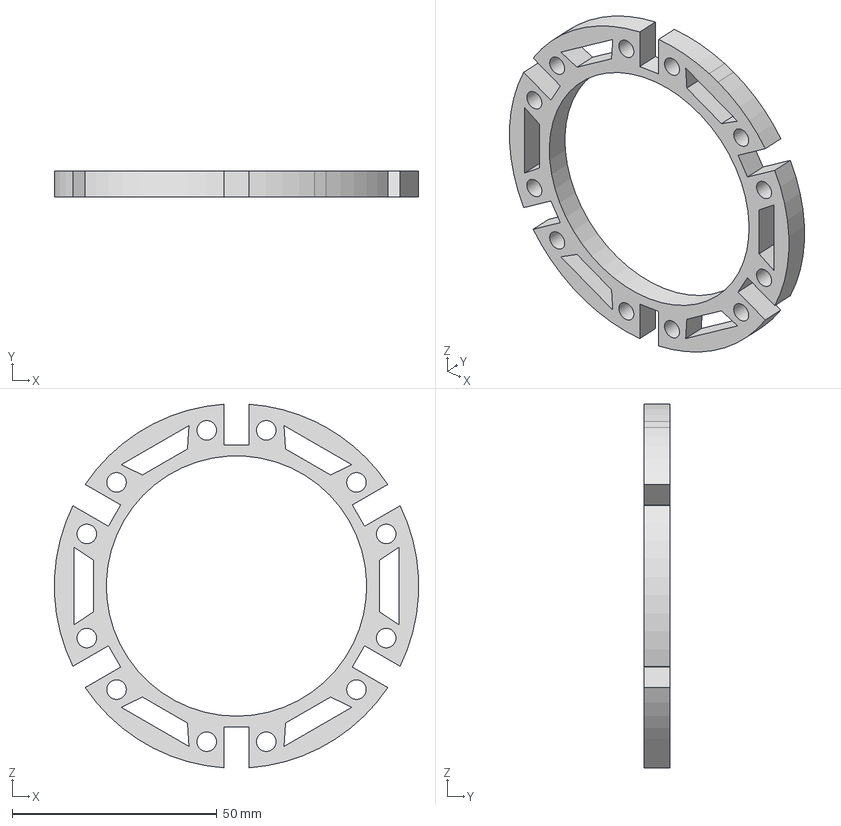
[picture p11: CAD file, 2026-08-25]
CAD/Parts/Front Hull and Nose - Full Ring.step
88.8 x 6.35 x 88.7 mm

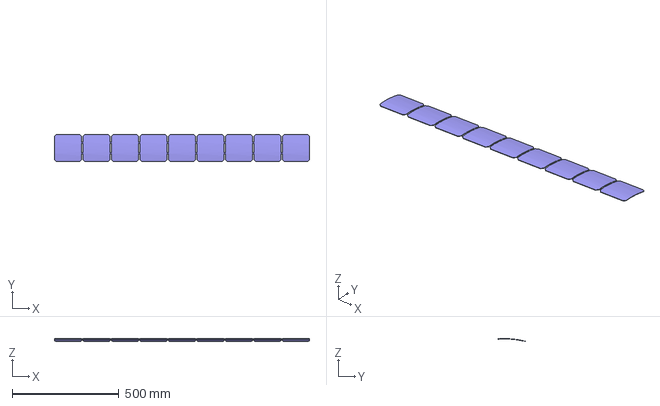
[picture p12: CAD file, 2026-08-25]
CAD/Parts/Wing - Solar Panels Main.step
1193.8 x 127.0 x 14.0 mm

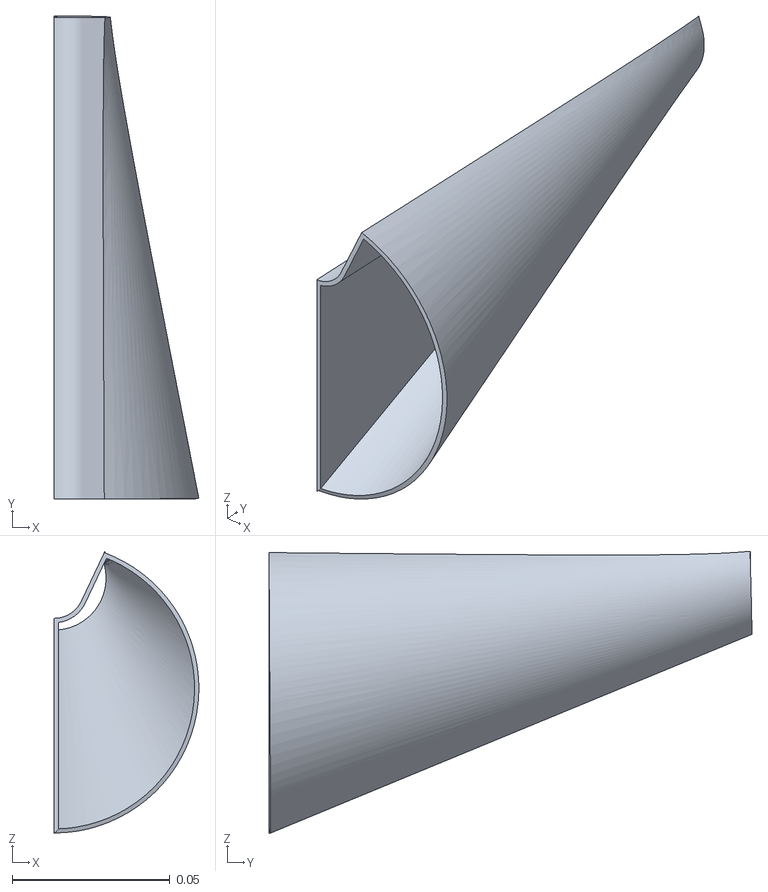
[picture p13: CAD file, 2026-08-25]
CAD/3D Prints/Pontoons - Rear Pontoon2.stl
0.0458 x 0.153 x 0.0894

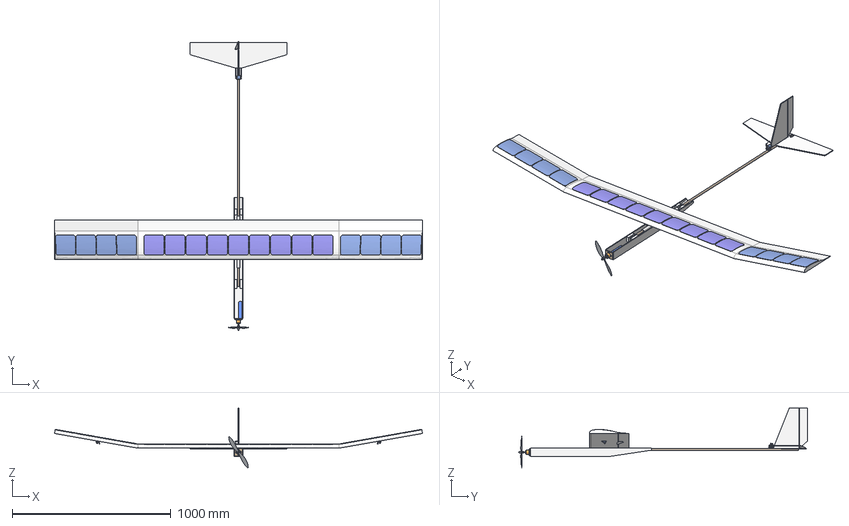
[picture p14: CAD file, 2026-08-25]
CAD/Assembled/Foam Version 1.step
2320.6 x 1821.0 x 378.1 mm
Control Horn x 4
Solar Panels Main
Wooden Dowel 48in
Solar Panels Wingtips x 2
Motor
SERVo x 4
Short Wooden Dowel
D2826 - Support__ DE 188745
Push/Pull Rod1 x 2
Push/Pull Rod2 x 2
Foam Spacer1 x 2
Servo Horn x 4
SPINNER V1 - Axe M5__ DE 196387
PVC Connector
Hull Foamy
Elevator and Rudder
Battery
Propeller
Wing
SPINNER V1 - Part1__ DE 193273
SPINNER V1 - Part3__ DE 195829
Foam Spacer2 x 2
Wooden Motor Mount

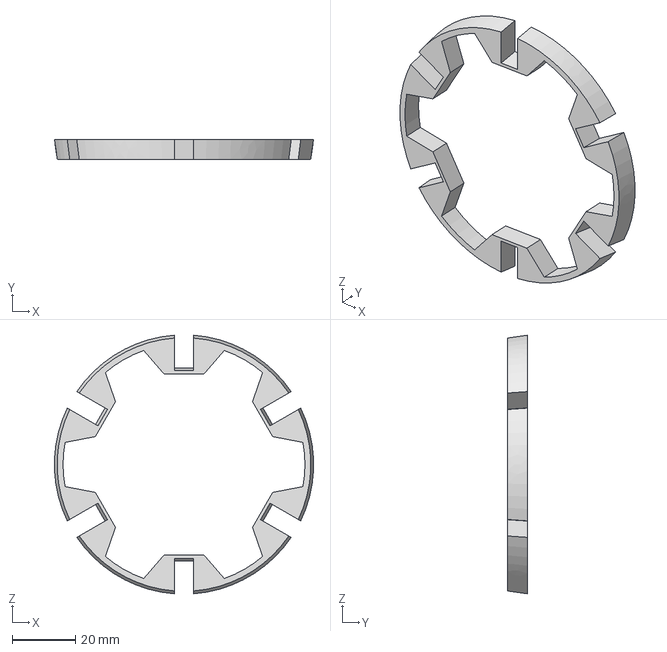
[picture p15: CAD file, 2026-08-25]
CAD/Parts/Front Hull and Nose - Nose Ring.step
81.6 x 6.35 x 81.5 mm

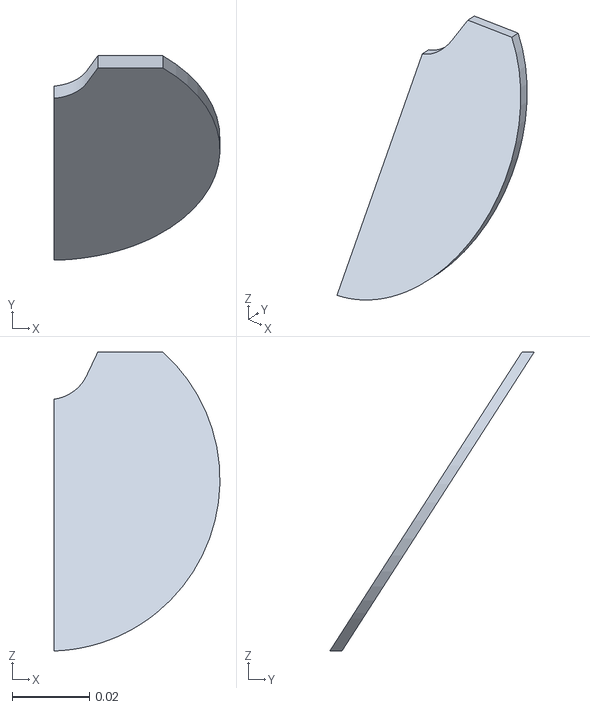
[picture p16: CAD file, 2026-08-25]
CAD/3D Prints/Pontoons - Pontoon Cap1.stl
0.043 x 0.0531 x 0.0776

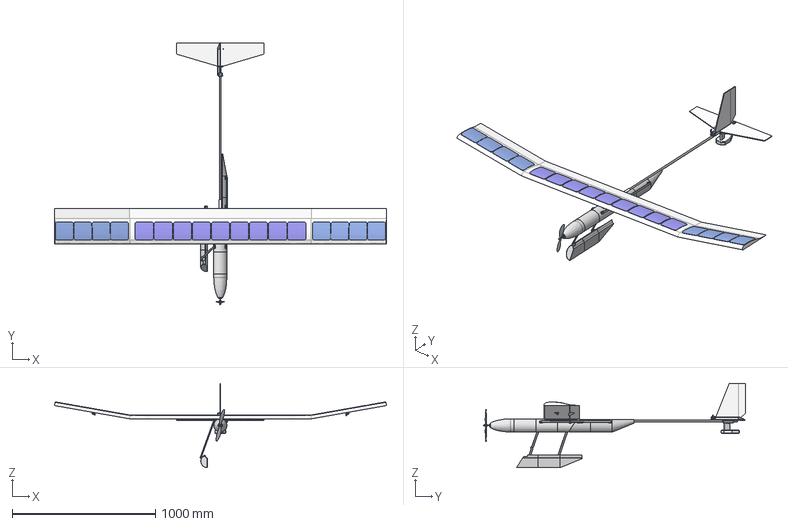
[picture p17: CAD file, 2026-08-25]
CAD/Assembled/Solar Plane V2.step
2320.6 x 1833.6 x 590.6 mm
Solar Panels Wingtips x 2
Wooden Dowel 48in
Motor
Propeller
Pontoon Cap2
Hinge Mount x 8
Wing
Servo Horn x 4
Pontoon Cap1
Dowel Ring x 4
D2826 - Support__ DE 188745
SERVo x 4
PVC Connector
Rear Pontoon1
Hinge Bar Notched x 2
Solar Panels Main
Push/Pull Rod2 x 2
SPINNER V1 - Part1__ DE 193273
Control Horn x 4
Hinge Bar x 2
Hull1
Push/Pull Rod1 x 2
Front Pontoon1
Full Ring x 2
Elevator and Rudder
SPINNER V1 - Axe M5__ DE 196387
Hull Connector x 4
Hull3
Cover
Front Pontoon2
Tail Bouy Mast
Nose Ring
Motor Mount
Nose Cone
Short Wooden Dowel
Rear Pontoon2
Middle Pontoon1
Foam Block
Middle Pontoon2
Hull2
SPINNER V1 - Part3__ DE 195829

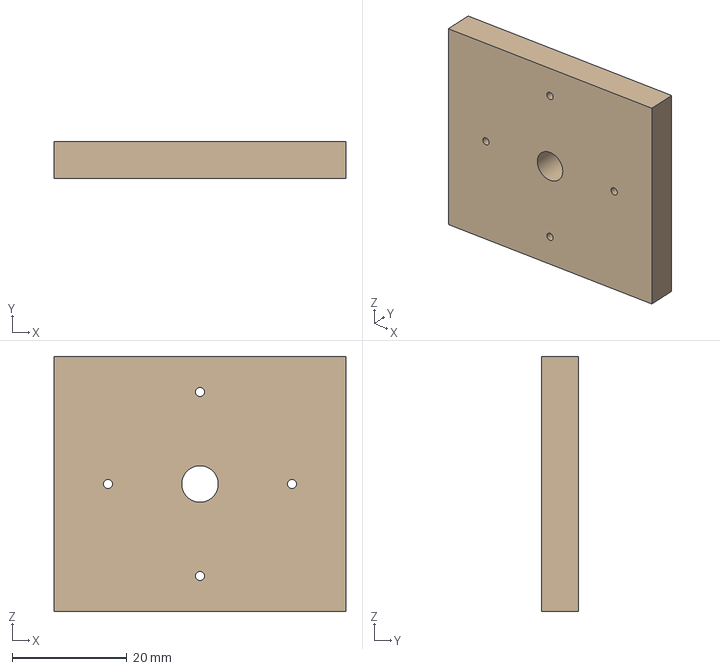
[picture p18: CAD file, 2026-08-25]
CAD/Parts/Motor Mount - Wooden Motor Mount.step
50.8 x 6.35 x 44.5 mm

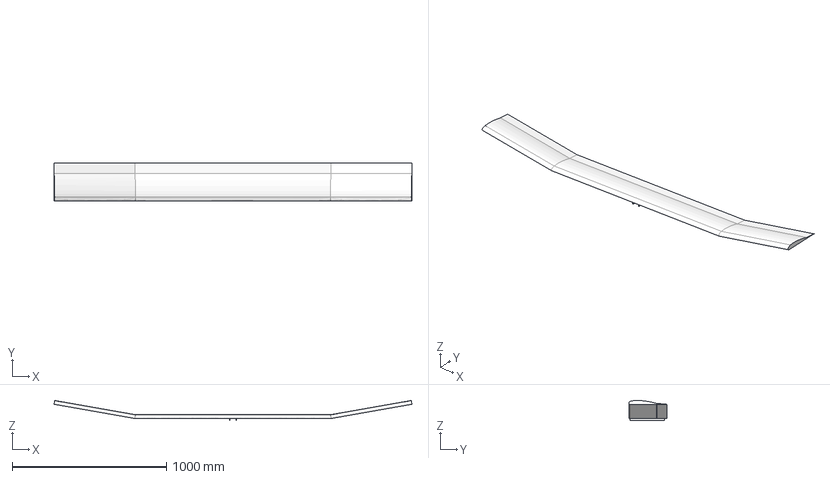
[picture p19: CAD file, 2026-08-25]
CAD/Parts/Wing - Wing.step
2320.6 x 249.1 x 130.2 mm

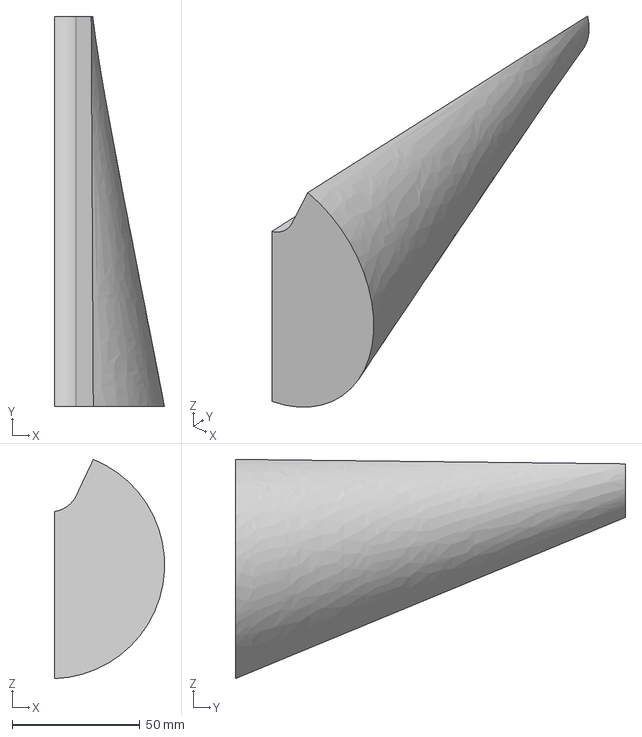
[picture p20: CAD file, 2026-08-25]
CAD/Parts/Pontoons - Rear Core2.step
43.0 x 152.4 x 85.7 mm

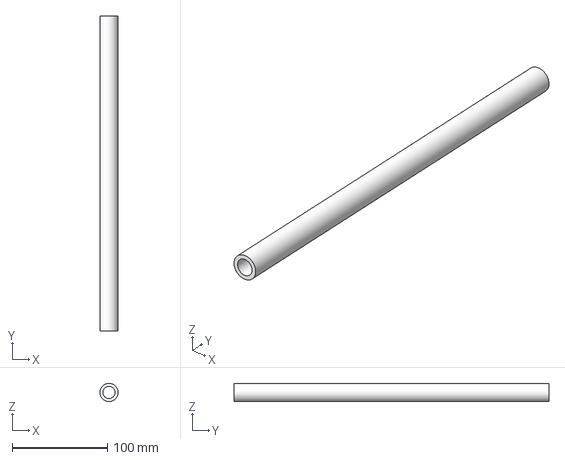
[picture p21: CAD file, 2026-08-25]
CAD/Parts/Wooden Rod - PVC Connector.step
19.0 x 330.2 x 19.0 mm

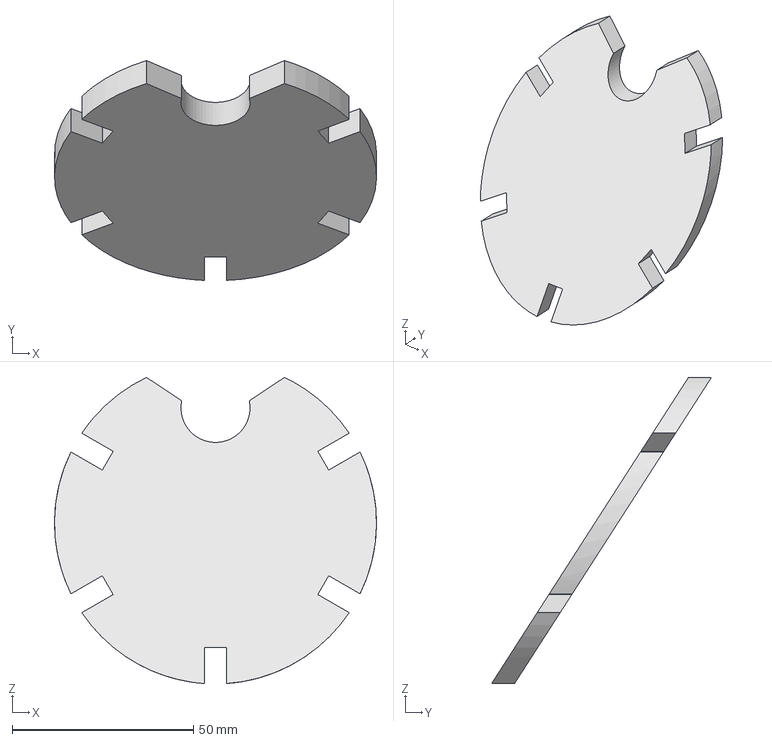
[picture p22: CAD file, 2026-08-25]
CAD/Parts/Front Hull and Nose - Cover.step
88.9 x 60.7 x 84.5 mm

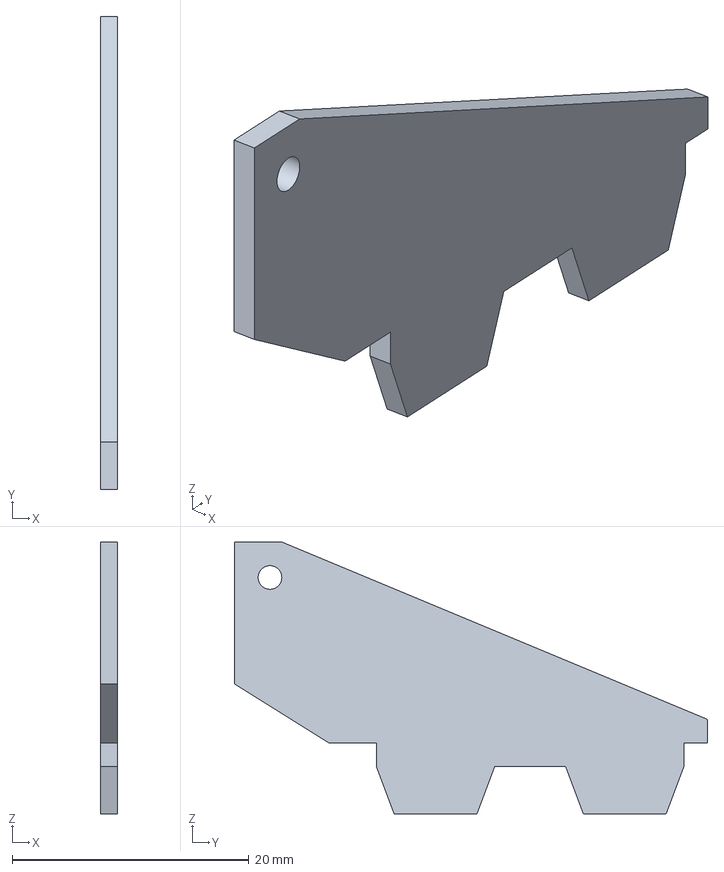
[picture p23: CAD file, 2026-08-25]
CAD/Parts/Control Horns - Control Horn.step
1.40 x 40.0 x 23.0 mm

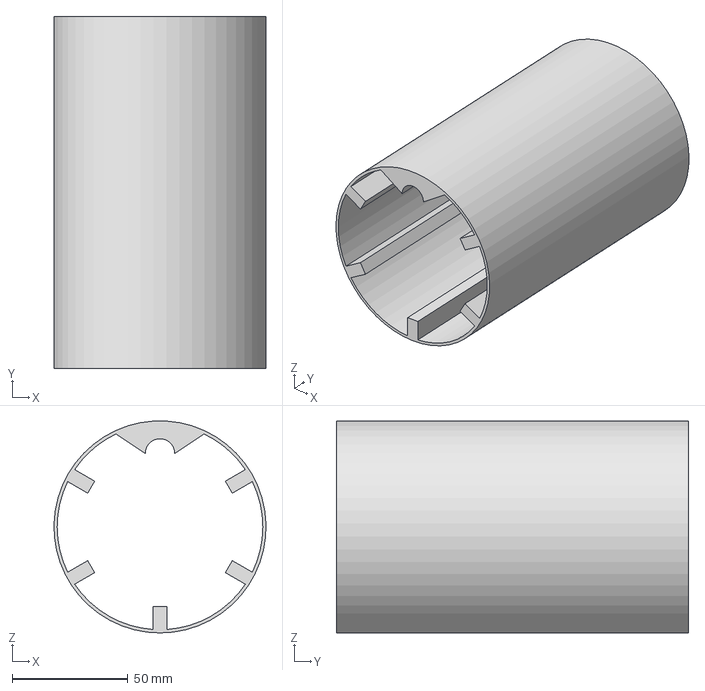
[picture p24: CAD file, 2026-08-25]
CAD/Parts/Front Hull and Nose - Hull2.step
91.7 x 152.4 x 91.6 mm

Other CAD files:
CAD/3D Prints/Pontoons - Pontoon Cap2.stl
CAD/Parts/Front Hull and Nose - Motor Mount.step
CAD/Parts/Front Hull and Nose - Hull1.step
CAD/Parts/Pontoons - Middle Pontoon1.step
CAD/3D Prints/Control Horns - Control Horn.stl
CAD/3D Prints/Front Hull and Nose - Cover.stl
CAD/3D Prints/Front Hull and Nose - Dowel Ring.stl
CAD/3D Prints/Front Hull and Nose - Full Ring.stl
CAD/3D Prints/Front Hull and Nose - Hull Connector.stl
CAD/3D Prints/Front Hull and Nose - Hull1.stl
CAD/3D Prints/Front Hull and Nose - Hull2.stl
CAD/3D Prints/Front Hull and Nose - Hull3.stl
CAD/3D Prints/Front Hull and Nose - Motor Mount.stl
CAD/3D Prints/Front Hull and Nose - Nose Cone.stl
CAD/3D Prints/Front Hull and Nose - Nose Ring.stl
CAD/3D Prints/Hinge Mount - Hinge Mount.stl
CAD/3D Prints/Pontoons - Front Pontoon1.stl
CAD/3D Prints/Pontoons - Front Pontoon2.stl
CAD/3D Prints/Pontoons - Middle Pontoon1.stl
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

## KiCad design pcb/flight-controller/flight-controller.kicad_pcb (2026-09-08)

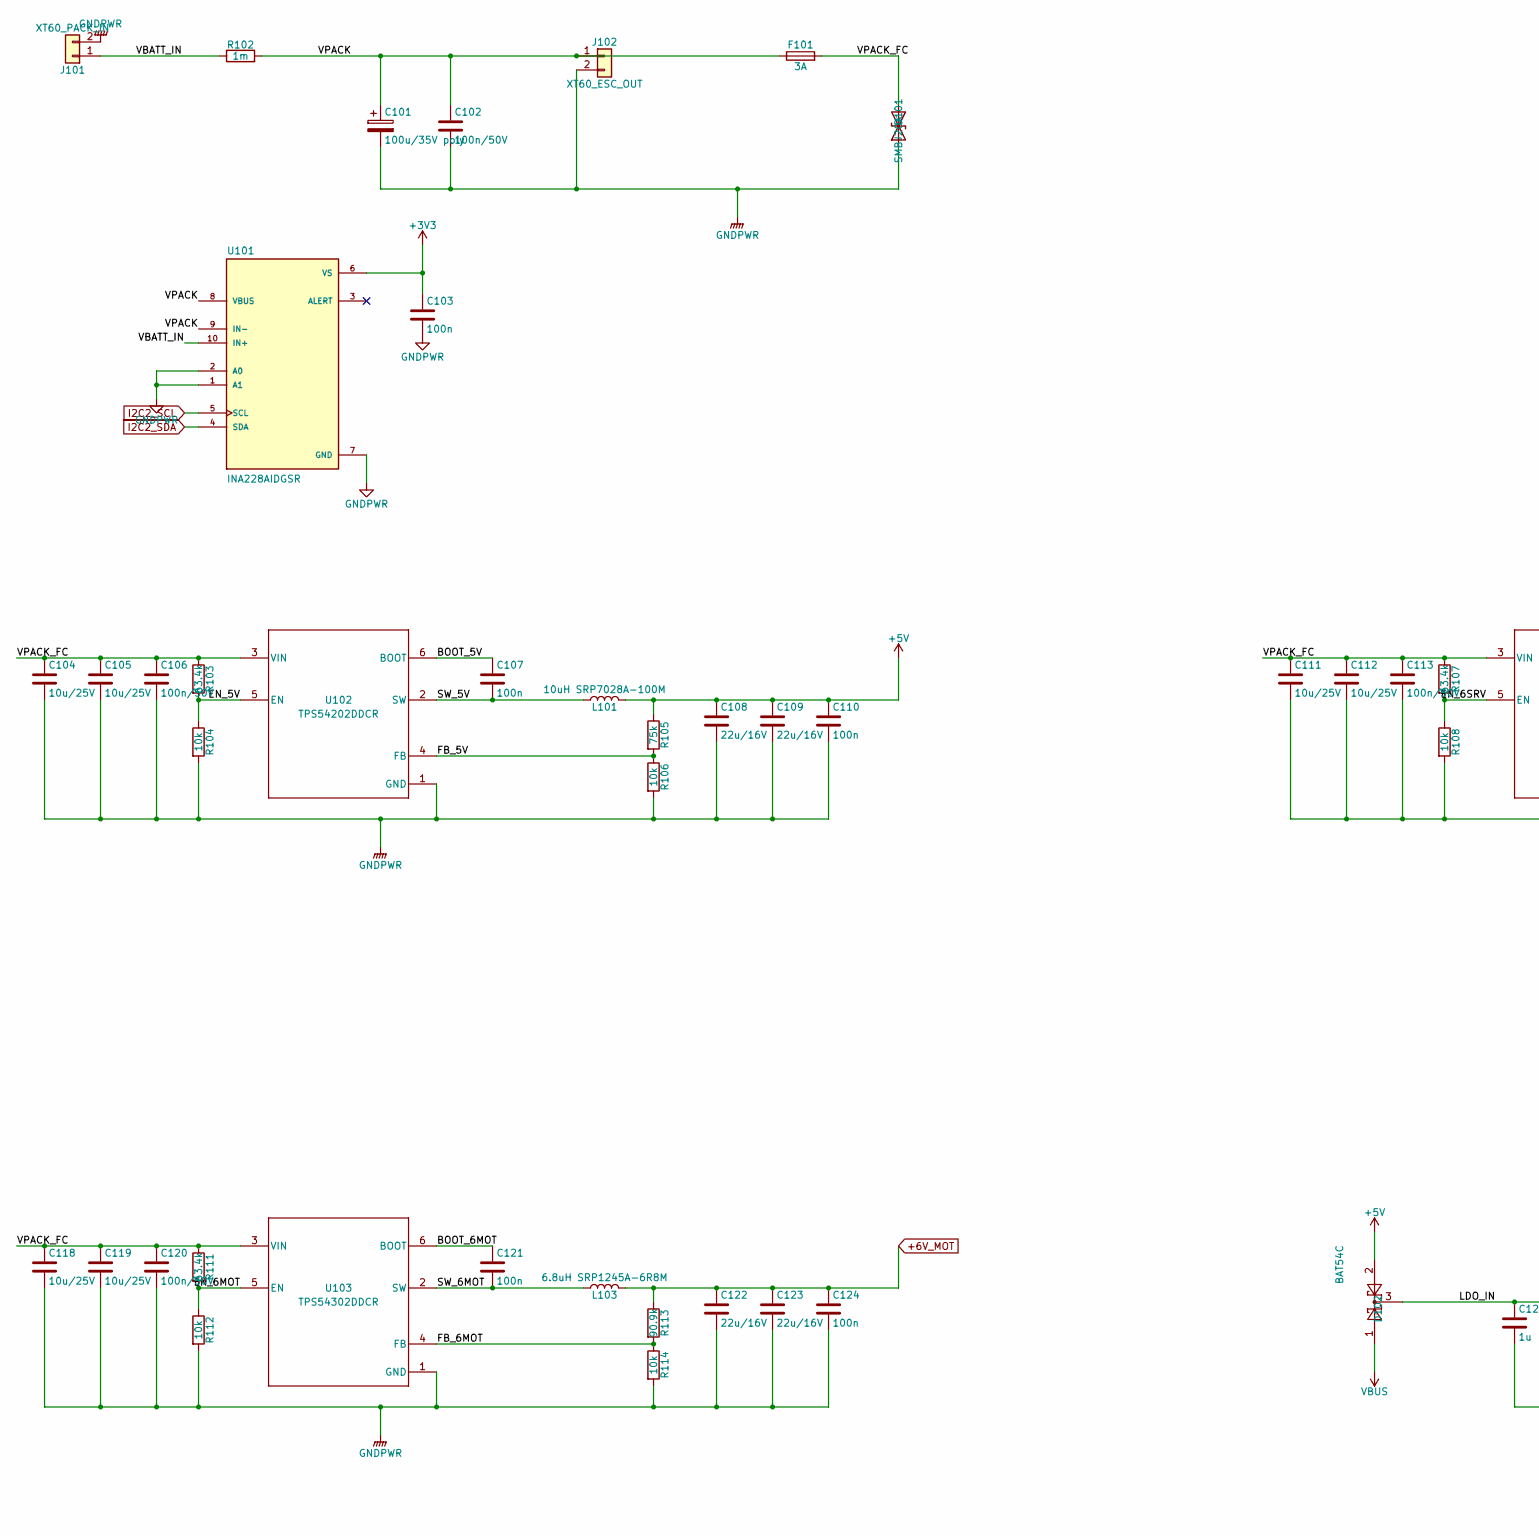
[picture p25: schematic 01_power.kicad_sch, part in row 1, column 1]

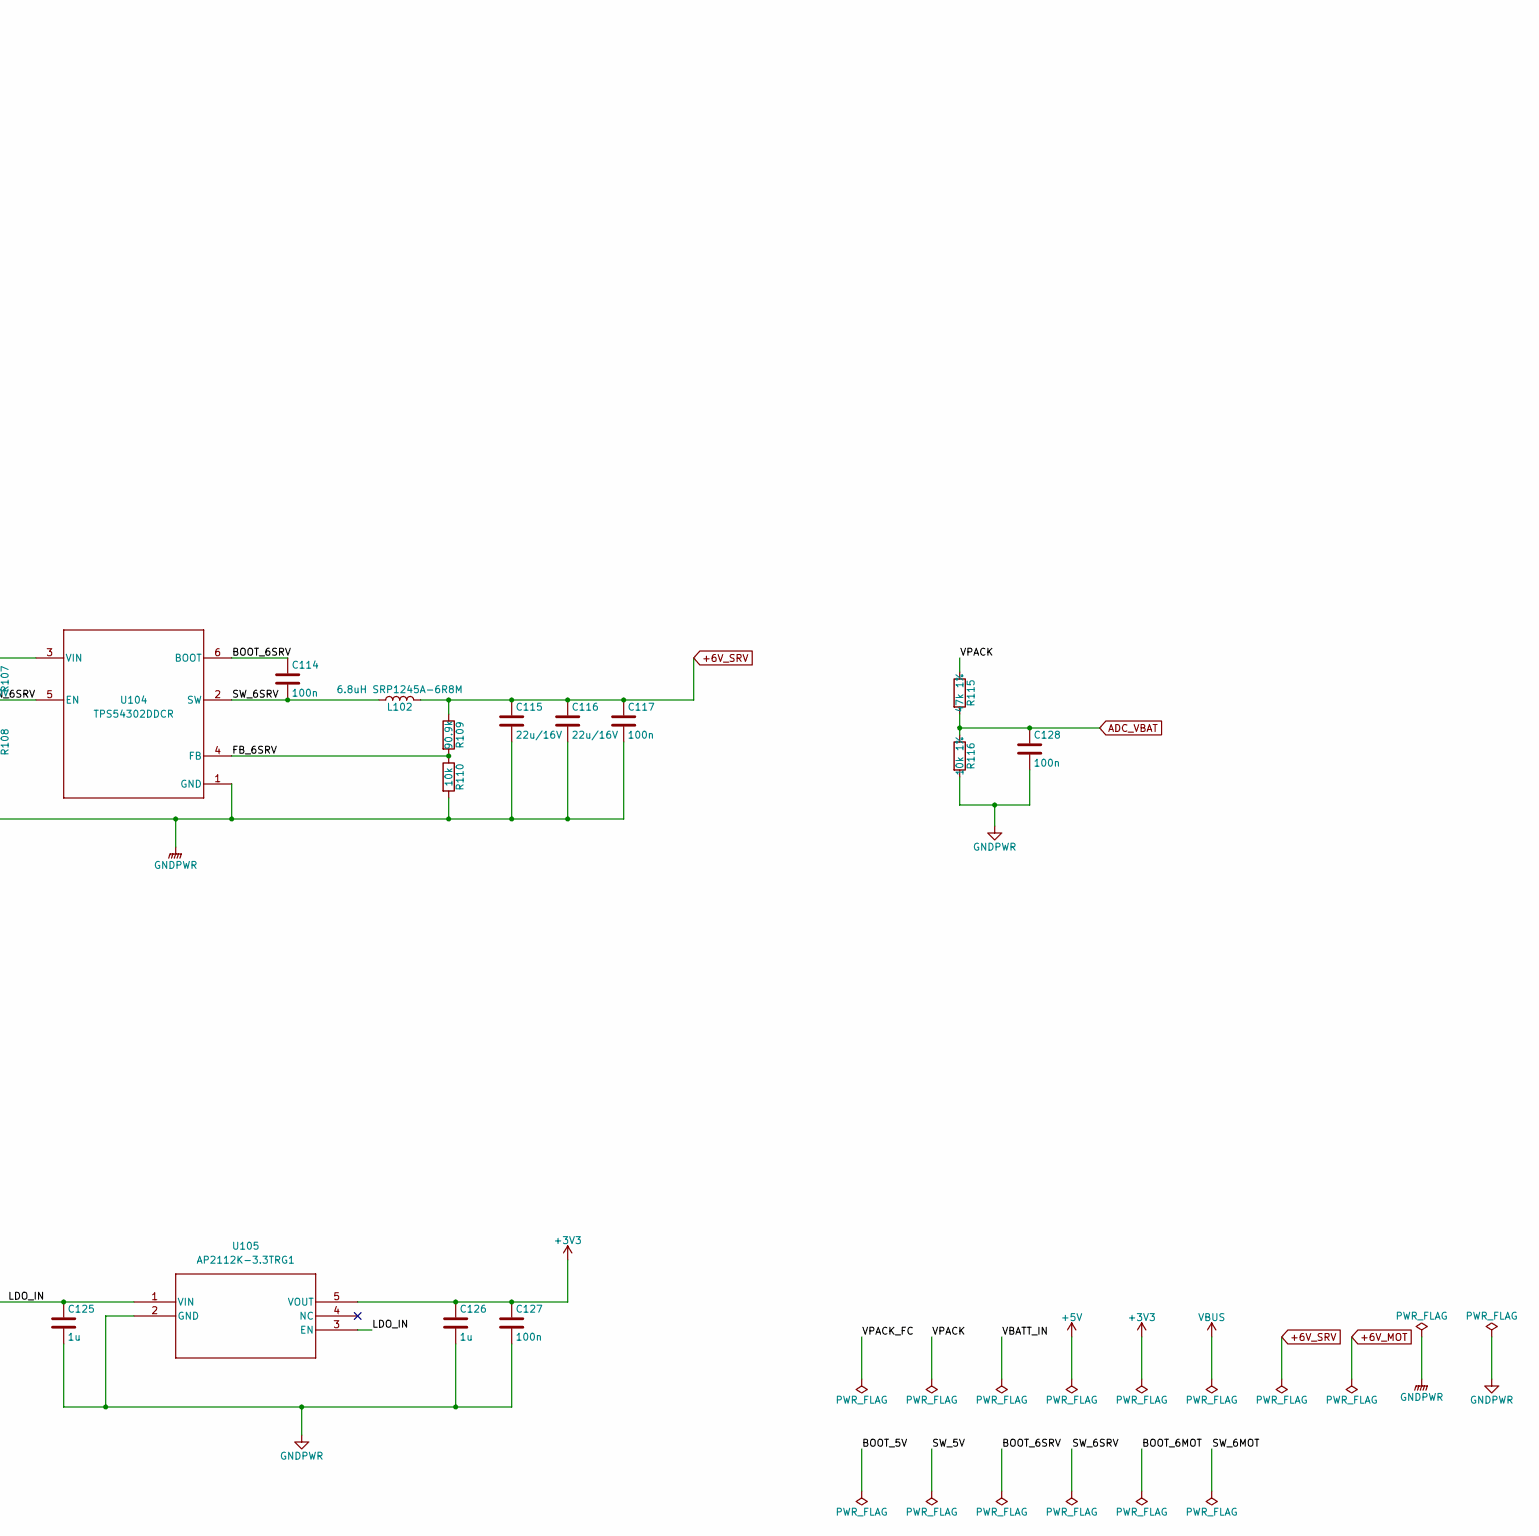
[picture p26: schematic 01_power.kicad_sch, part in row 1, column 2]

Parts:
C101: 100u/35V poly; CP_EIA-7343-31_Kemet-D
C102, C106, C113, C120: 100n/50V; C_0603_1608Metric
C103, C107, C110, C114, C117, C121, C124, C127, C128: 100n; C_0603_1608Metric
C104, C105, C111, C112, C118, C119: 10u/25V; C_1210_3225Metric
C108, C109, C115, C116, C122, C123: 22u/16V; C_1210_3225Metric
C125, C126: 1u; C_0805_2012Metric
D101: SMBJ20A; D_SMB
D102: BAT54C; SOT-23
F101: 3A; Fuse_1206_3216Metric
J101: XT60_PACK_IN; AMASS_XT60PW-F_1x02_P7.20mm_Horizontal
J102: XT60_ESC_OUT; AMASS_XT60PW-F_1x02_P7.20mm_Horizontal
L101: 10uH SRP7028A-100M; L_Bourns_SRP7028A_7.3x6.6mm
L102, L103: 6.8uH SRP1245A-6R8M; L_Bourns_SRP1245A
R102: 1m; R_2512_6332Metric
R103, R107, R111: 63.4k; R_0603_1608Metric
R104, R106, R108, R110, R112, R114: 10k; R_0603_1608Metric
R105: 75k; R_0603_1608Metric
R109, R113: 90.9k; R_0603_1608Metric
R115: 47k 1%; R_0603_1608Metric
R116: 10k 1%; R_0603_1608Metric
U101: INA228AIDGSR; SOP50P490X110-10N
U102: TPS54202DDCR; DDC0006A_N
U103, U104: TPS54302DDCR; DDC0006A_N
U105: AP2112K-3.3TRG1; SOT_RG1_DIO

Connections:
/01_POWER/EN_5V: R103.2, R104.1, U102.5 (EN)
/01_POWER/EN_6MOT: R111.2, R112.1, U103.5 (EN)
/01_POWER/EN_6SRV: R107.2, R108.1, U104.5 (EN)
/01_POWER/FB_5V: R105.2, R106.1, U102.4 (FB)
/01_POWER/FB_6MOT: R113.2, R114.1, U103.4 (FB)
/01_POWER/FB_6SRV: R109.2, R110.1, U104.4 (FB)
/01_POWER/LDO_IN: C125.1, D102.3, U105.1 (VIN), U105.3 (EN)
ADC_VBAT: C128.1, R115.2, R116.1; also elsewhere on the board
I2C2_SCL: U101.5 (SCL); also elsewhere on the board
I2C2_SDA: U101.4 (SDA); also elsewhere on the board

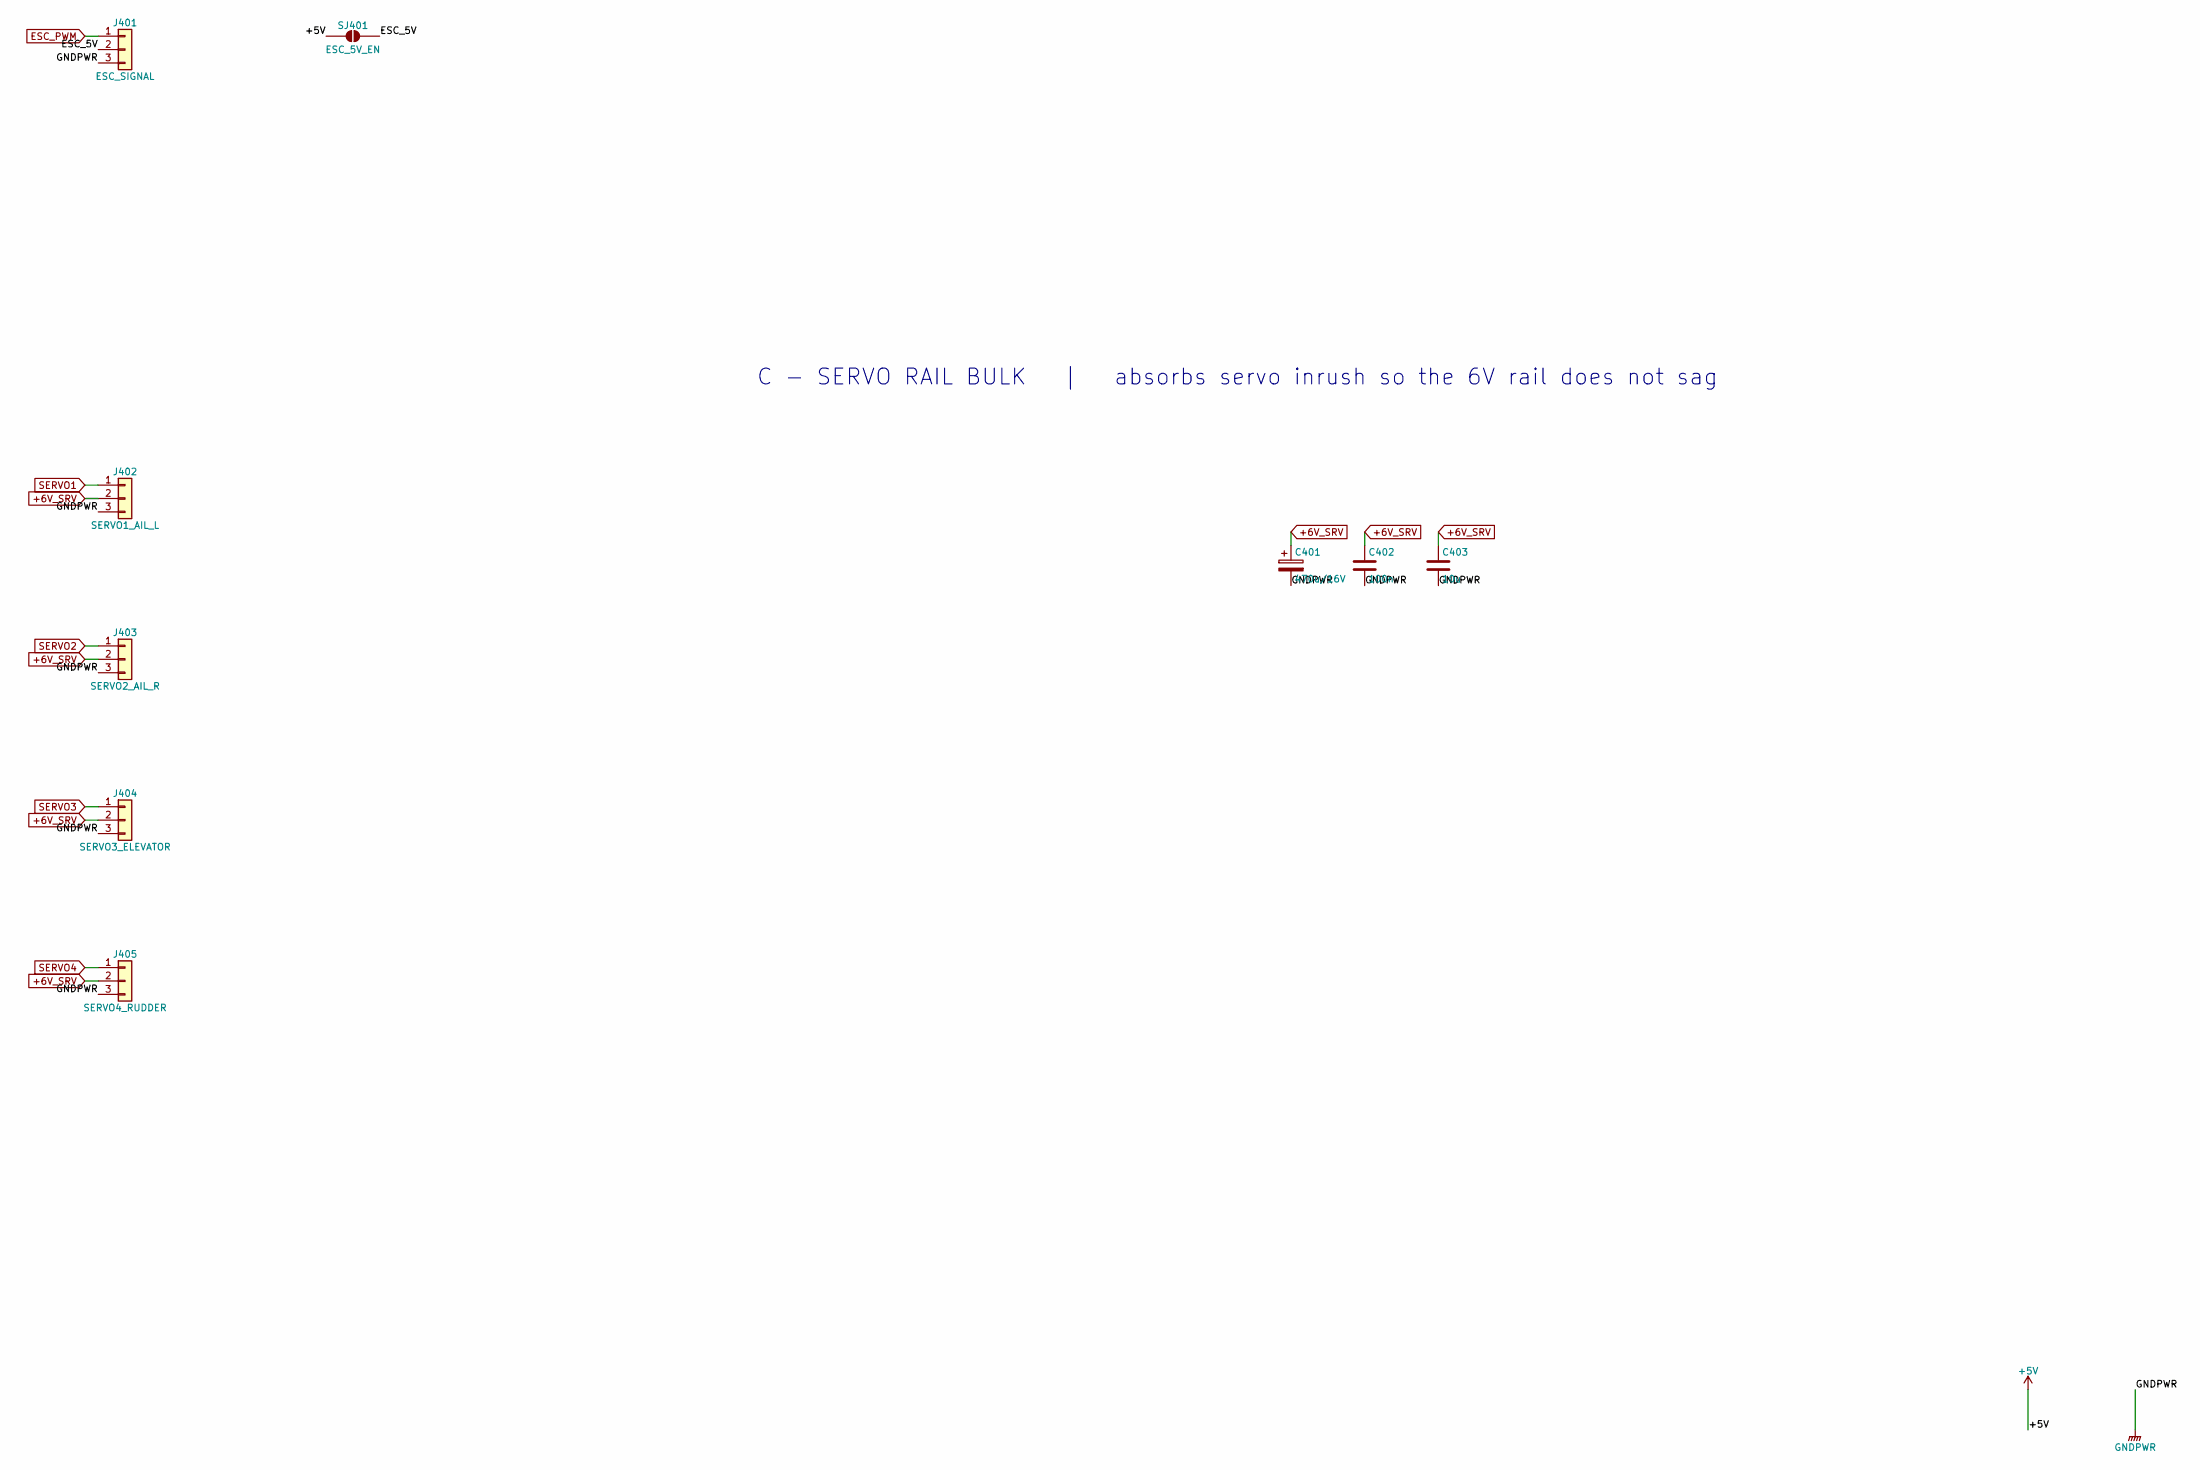
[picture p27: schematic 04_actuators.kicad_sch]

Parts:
C401: 470u/16V; CP_Elec_8x10.5
C402: 100n; C_0603_1608Metric
C403: 10u; C_1210_3225Metric
J401: ESC_SIGNAL; PinHeader_1x03_P2.54mm_Vertical
J402: SERVO1_AIL_L; PinHeader_1x03_P2.54mm_Vertical
J403: SERVO2_AIL_R; PinHeader_1x03_P2.54mm_Vertical
J404: SERVO3_ELEVATOR; PinHeader_1x03_P2.54mm_Vertical
J405: SERVO4_RUDDER; PinHeader_1x03_P2.54mm_Vertical
SJ401: ESC_5V_EN; SolderJumper-2_P1.3mm_Open_Pad1.0x1.5mm

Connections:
/04_ACTUATORS/ESC_5V: J401.2, SJ401.2 (B)
ESC_PWM: J401.1; also elsewhere on the board
SERVO1: J402.1; also elsewhere on the board
SERVO2: J403.1; also elsewhere on the board
SERVO3: J404.1; also elsewhere on the board
SERVO4: J405.1; also elsewhere on the board

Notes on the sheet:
C - SERVO RAIL BULK | absorbs servo inrush so the 6V rail does not sag

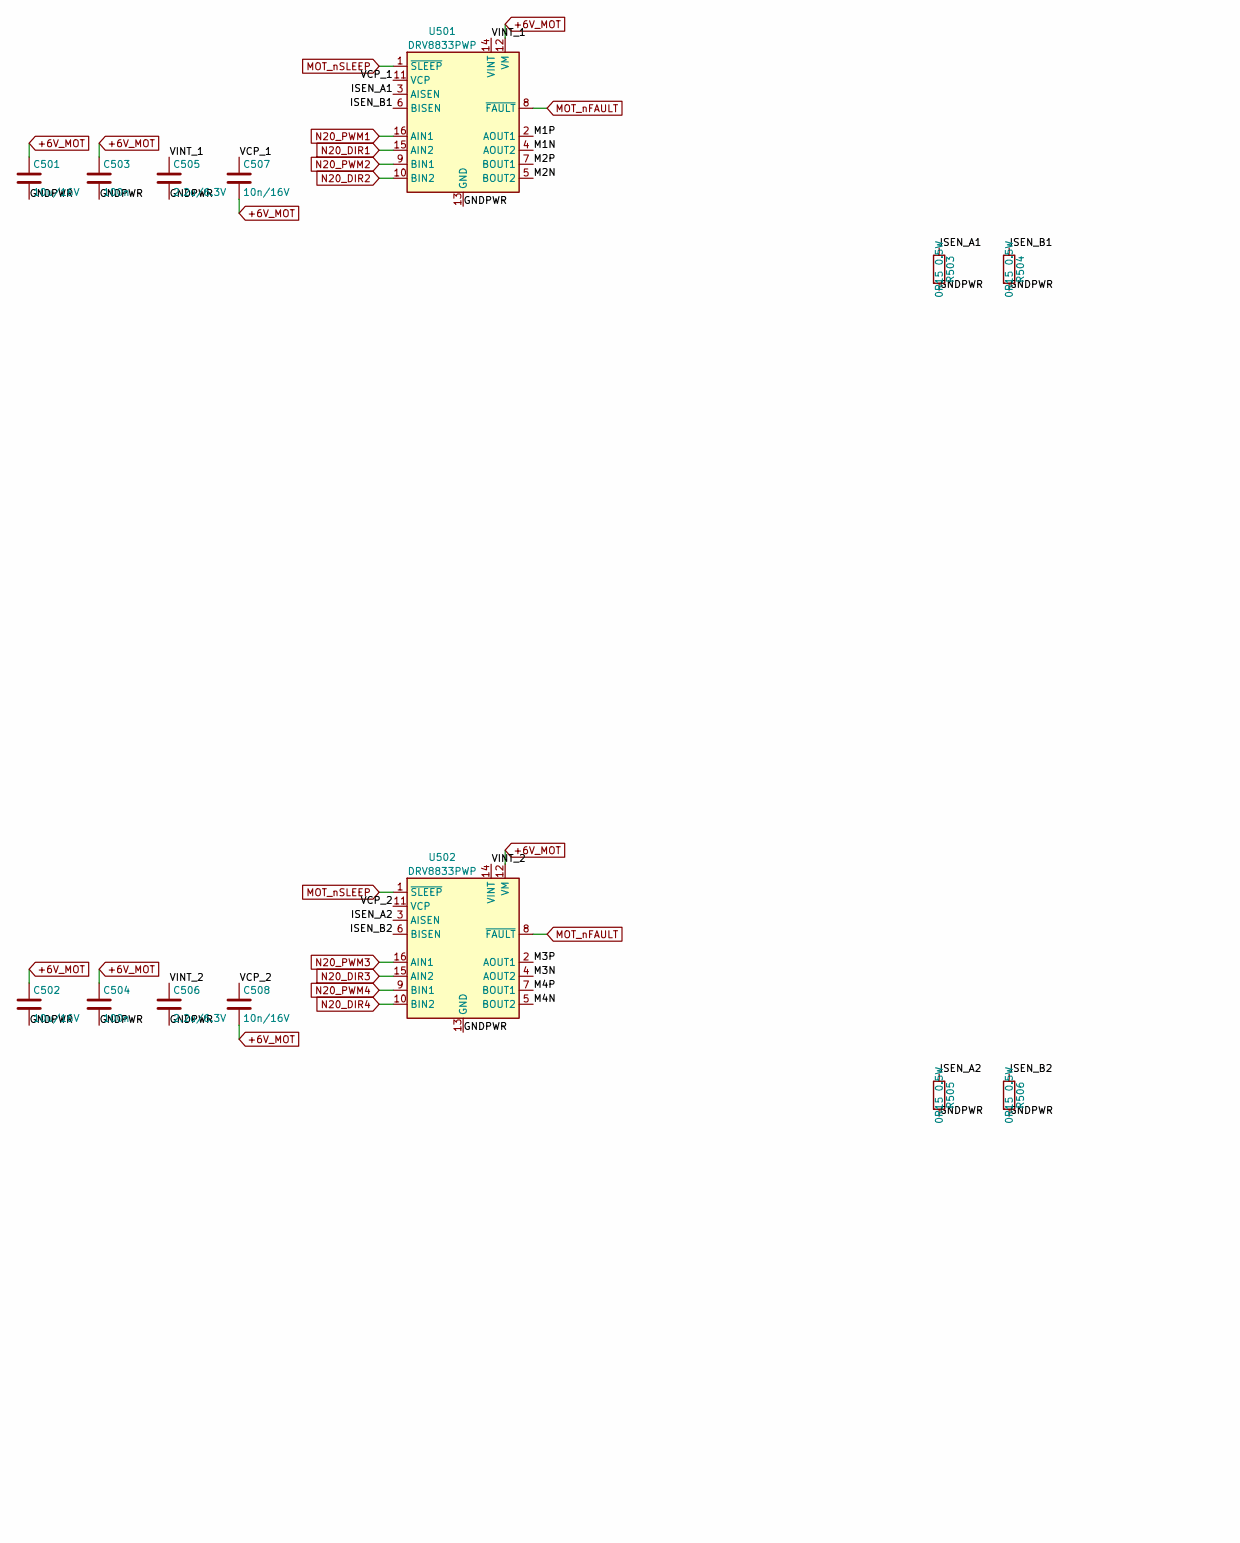
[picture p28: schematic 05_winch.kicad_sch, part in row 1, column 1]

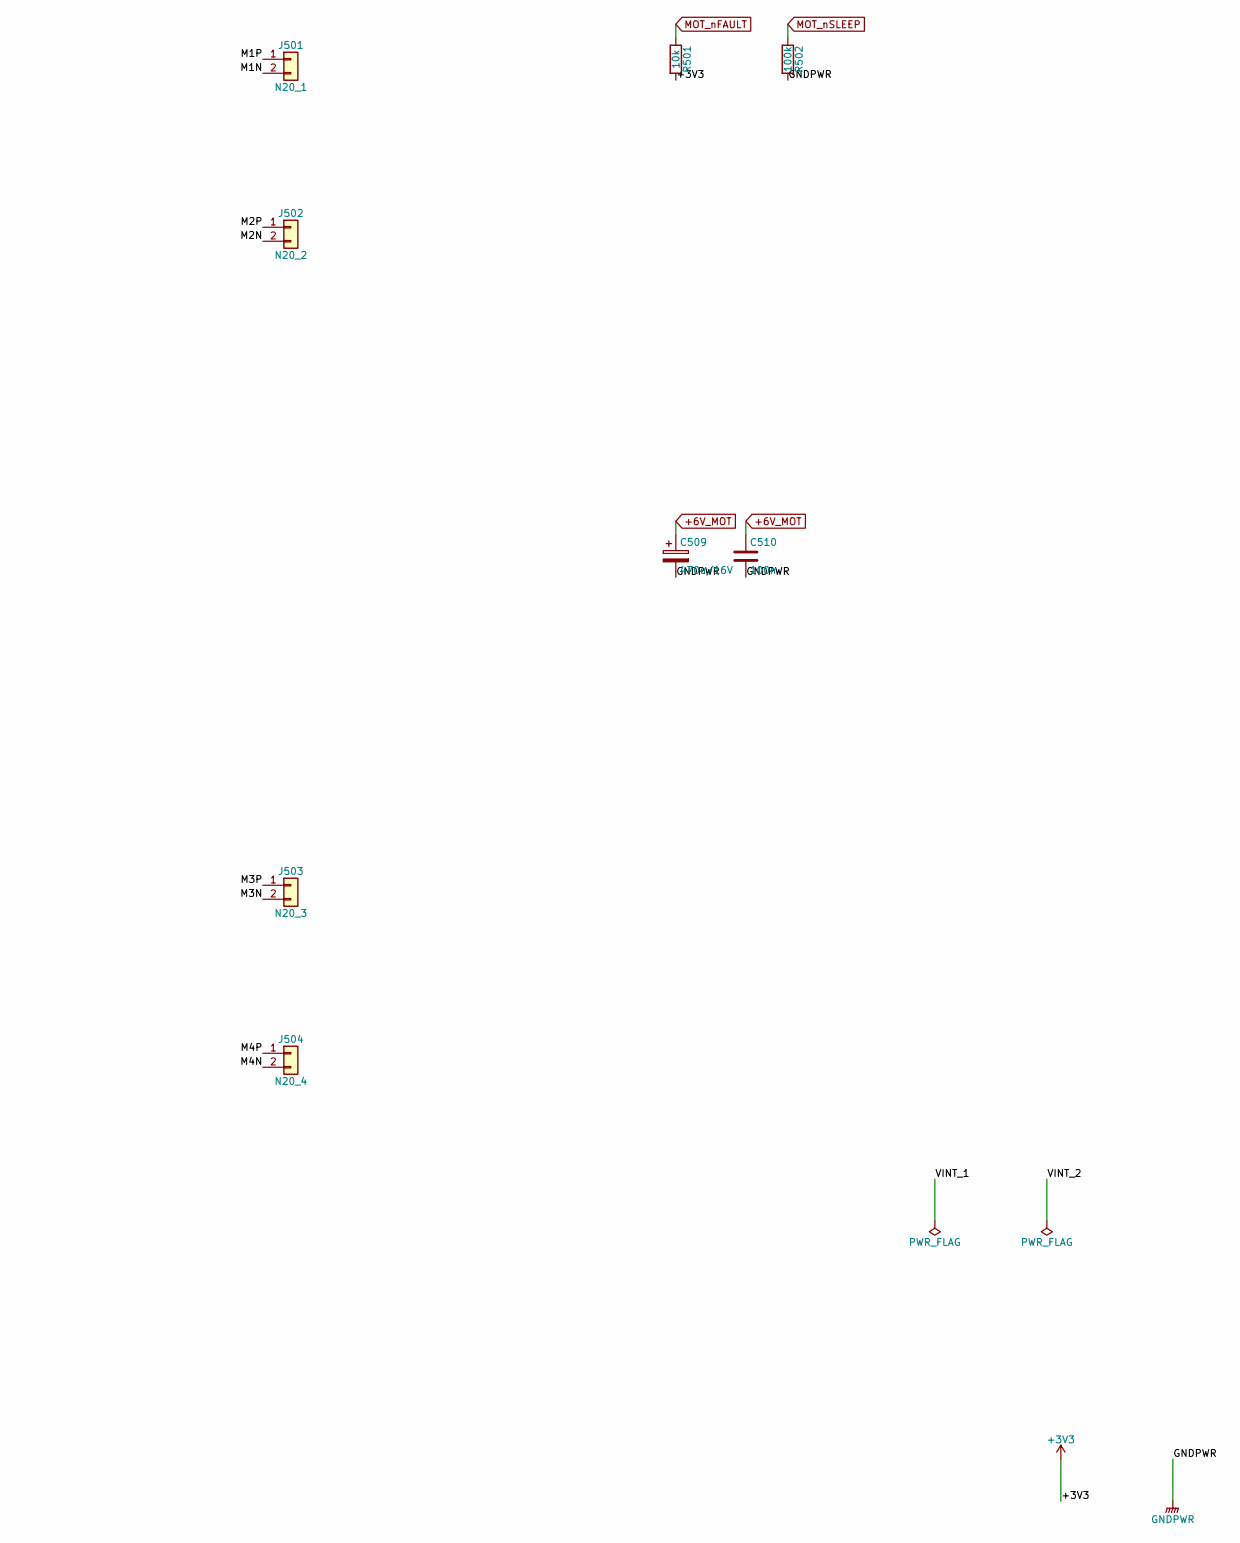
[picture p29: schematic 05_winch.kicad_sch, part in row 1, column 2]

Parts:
C501, C502: 10u/16V; C_1210_3225Metric
C503, C504, C510: 100n; C_0603_1608Metric
C505, C506: 2.2u/6.3V; C_0603_1608Metric
C507, C508: 10n/16V; C_0603_1608Metric
C509: 470u/16V; CP_Elec_8x10.5
J501: N20_1; JST_PH_S2B-PH-K_1x02_P2.00mm_Horizontal
J502: N20_2; JST_PH_S2B-PH-K_1x02_P2.00mm_Horizontal
J503: N20_3; JST_PH_S2B-PH-K_1x02_P2.00mm_Horizontal
J504: N20_4; JST_PH_S2B-PH-K_1x02_P2.00mm_Horizontal
R501: 10k; R_0603_1608Metric
R502: 100k; R_0603_1608Metric
R503, R504, R505, R506: 0R15 0.5W; R_1206_3216Metric
U501, U502: DRV8833PWP; HTSSOP-16-1EP_4.4x5mm_P0.65mm_EP3.4x5mm_Mask2.46x2.31mm_The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

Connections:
/05_WINCH/ISEN_A1: R503.1, U501.3 (AISEN)
/05_WINCH/ISEN_A2: R505.1, U502.3 (AISEN)
/05_WINCH/ISEN_B1: R504.1, U501.6 (BISEN)
/05_WINCH/ISEN_B2: R506.1, U502.6 (BISEN)
/05_WINCH/M1N: J501.2, U501.4 (AOUT2)
/05_WINCH/M1P: J501.1, U501.2 (AOUT1)
/05_WINCH/M2N: J502.2, U501.5 (BOUT2)
/05_WINCH/M2P: J502.1, U501.7 (BOUT1)
/05_WINCH/M3N: J503.2, U502.4 (AOUT2)
/05_WINCH/M3P: J503.1, U502.2 (AOUT1)
/05_WINCH/M4N: J504.2, U502.5 (BOUT2)
/05_WINCH/M4P: J504.1, U502.7 (BOUT1)
/05_WINCH/VCP_1: C507.1, U501.11 (VCP)
/05_WINCH/VCP_2: C508.1, U502.11 (VCP)
MOT_nFAULT: R501.1, U501.8 (~FAULT), U502.8 (~FAULT); also elsewhere on the board
MOT_nSLEEP: R502.1, U501.1 (~SLEEP), U502.1 (~SLEEP); also elsewhere on the board
N20_DIR1: U501.15 (AIN2); also elsewhere on the board
N20_DIR2: U501.10 (BIN2); also elsewhere on the board
N20_DIR3: U502.15 (AIN2); also elsewhere on the board
N20_DIR4: U502.10 (BIN2); also elsewhere on the board
N20_PWM1: U501.16 (AIN1); also elsewhere on the board
N20_PWM2: U501.9 (BIN1); also elsewhere on the board
N20_PWM3: U502.16 (AIN1); also elsewhere on the board
N20_PWM4: U502.9 (BIN1); also elsewhere on the board

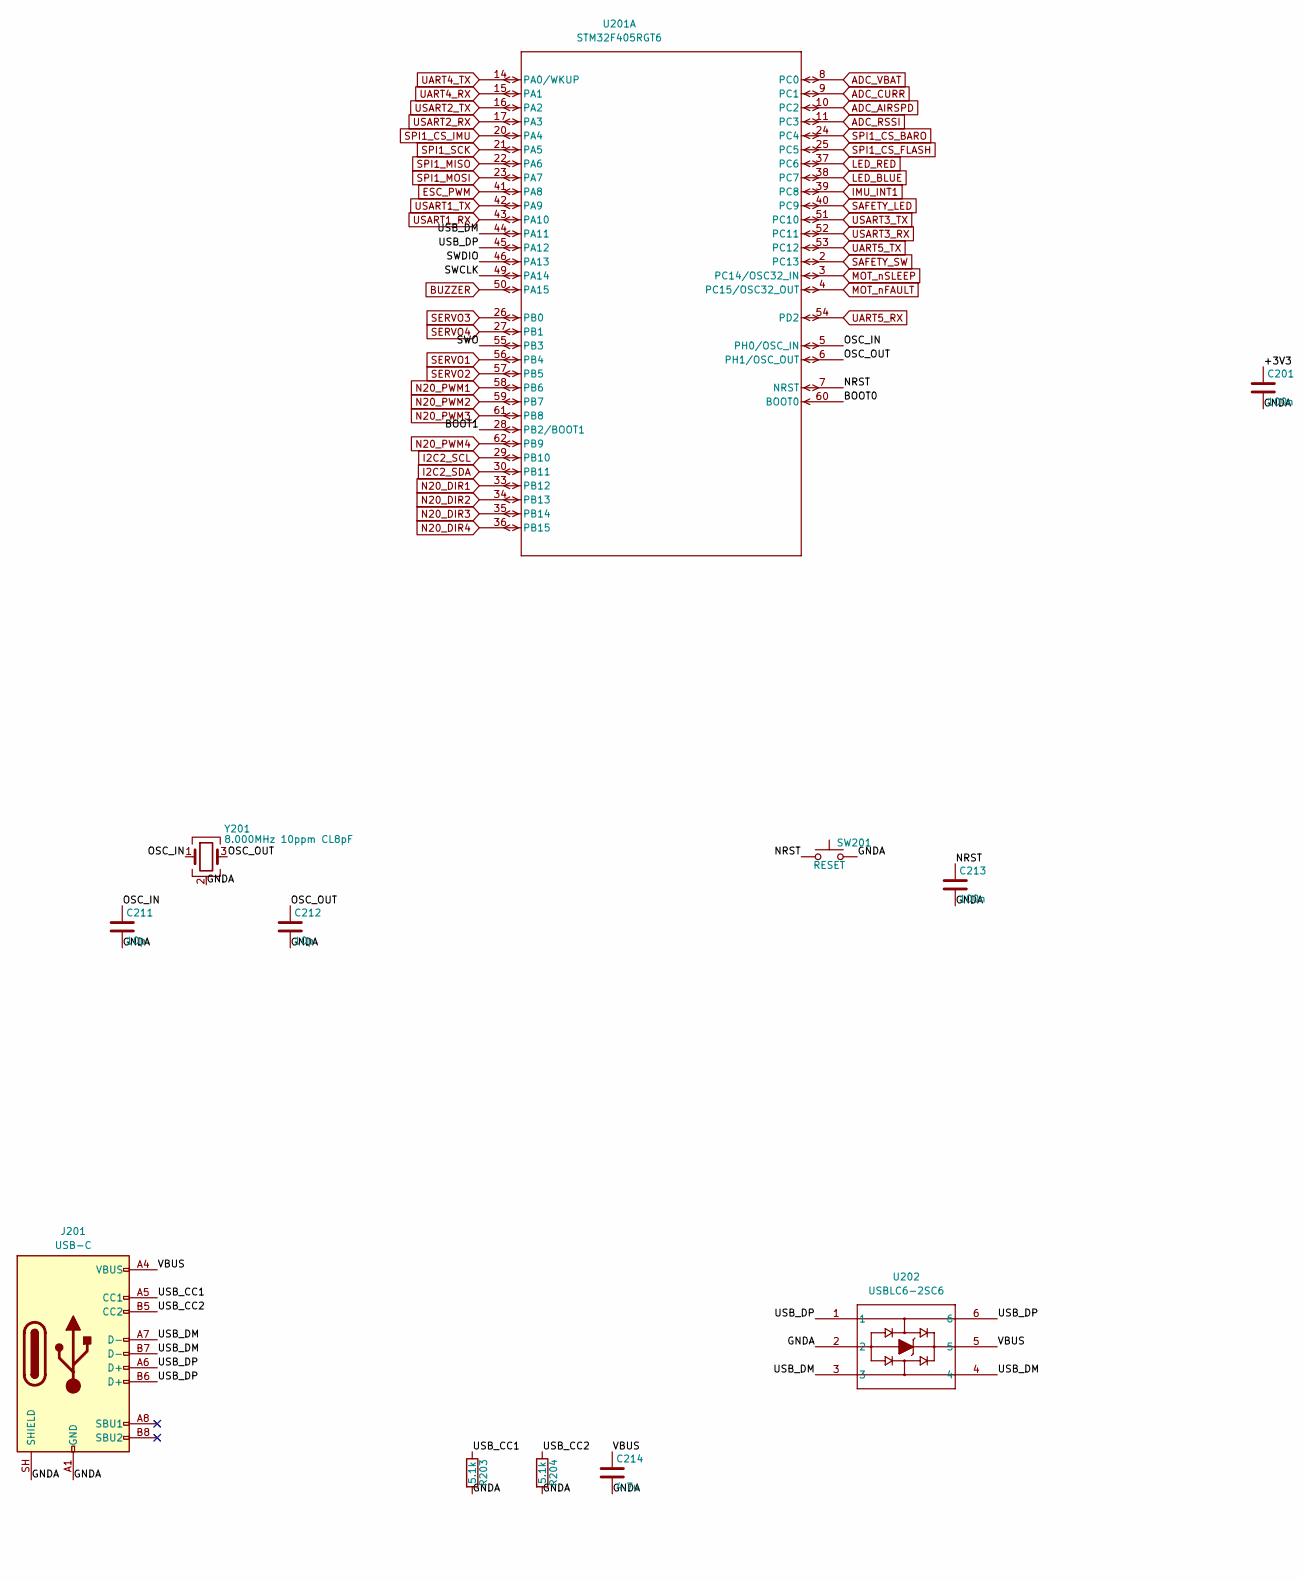
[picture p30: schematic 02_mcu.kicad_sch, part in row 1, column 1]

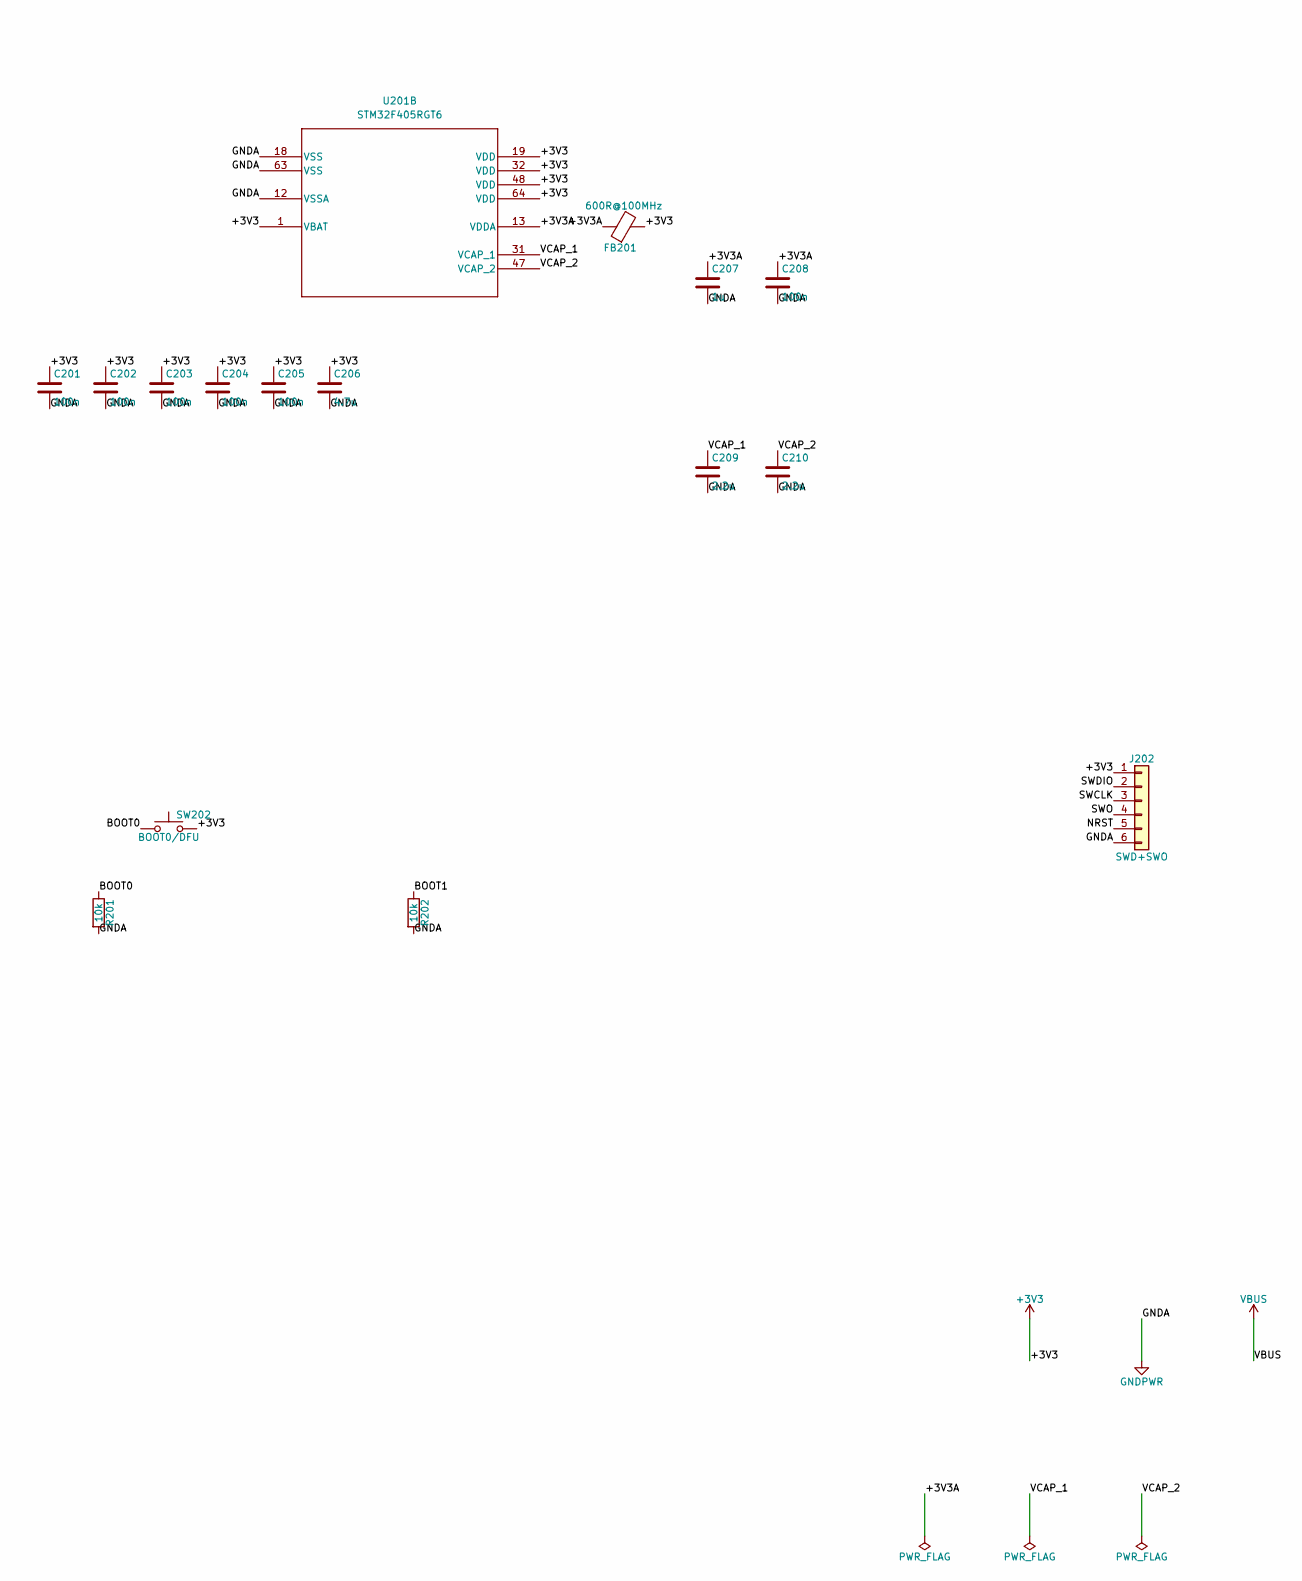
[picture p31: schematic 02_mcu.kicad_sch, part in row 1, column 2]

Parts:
C201, C202, C203, C204, C205, C208, C213: 100n; C_0402_1005Metric
C206, C214: 4.7u; C_0805_2012Metric
C207: 1u; C_0603_1608Metric
C209, C210: 2.2u; C_0603_1608Metric
C211, C212: 10p; C_0402_1005Metric
FB201: 600R@100MHz; L_0805_2012Metric
J201: USB-C; USB_C_Receptacle_GCT_USB4085
J202: SWD+SWO; PinHeader_1x06_P1.27mm_Vertical
R201, R202: 10k; R_0603_1608Metric
R203, R204: 5.1k; R_0402_1005Metric
SW201: RESET; SW_SPST_B3S-1000
SW202: BOOT0/DFU; SW_SPST_B3S-1000
U201: STM32F405RGT6; LQFP64-10x10mm
U202: USBLC6-2SC6; SOT23-6L_STM
Y201: 8.000MHz 10ppm CL8pF; Crystal_SMD_3225-4Pin_3.2x2.5mm

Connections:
/02_MCU/BOOT0: R201.1, SW202.1, U201.60 (BOOT0)
/02_MCU/BOOT1: R202.1, U201.28 (PB2/BOOT1)
/02_MCU/NRST: C213.1, J202.5, SW201.1, U201.7 (NRST)
/02_MCU/OSC_IN: C211.1, U201.5 (PH0/OSC_IN), Y201.1
/02_MCU/OSC_OUT: C212.1, U201.6 (PH1/OSC_OUT), Y201.3
/02_MCU/SWCLK: J202.3, U201.49 (PA14)
/02_MCU/SWDIO: J202.2, U201.46 (PA13)
/02_MCU/SWO: J202.4, U201.55 (PB3)
/02_MCU/USB_CC1: J201.A5 (CC1), R203.1
/02_MCU/USB_CC2: J201.B5 (CC2), R204.1
/02_MCU/USB_DM: J201.A7 (D-), J201.B7 (D-), U201.44 (PA11), U202.3, U202.4
/02_MCU/USB_DP: J201.A6 (D+), J201.B6 (D+), U201.45 (PA12), U202.1, U202.6
ADC_AIRSPD: U201.10 (PC2); also elsewhere on the board
ADC_CURR: U201.9 (PC1); also elsewhere on the board
ADC_RSSI: U201.11 (PC3); also elsewhere on the board
ADC_VBAT: U201.8 (PC0); also elsewhere on the board
BUZZER: U201.50 (PA15); also elsewhere on the board
ESC_PWM: U201.41 (PA8); also elsewhere on the board
I2C2_SCL: U201.29 (PB10); also elsewhere on the board
I2C2_SDA: U201.30 (PB11); also elsewhere on the board
IMU_INT1: U201.39 (PC8); also elsewhere on the board
LED_BLUE: U201.38 (PC7); also elsewhere on the board
LED_RED: U201.37 (PC6); also elsewhere on the board
MOT_nFAULT: U201.4 (PC15/OSC32_OUT); also elsewhere on the board
MOT_nSLEEP: U201.3 (PC14/OSC32_IN); also elsewhere on the board
N20_DIR1: U201.33 (PB12); also elsewhere on the board
N20_DIR2: U201.34 (PB13); also elsewhere on the board
N20_DIR3: U201.35 (PB14); also elsewhere on the board
N20_DIR4: U201.36 (PB15); also elsewhere on the board
N20_PWM1: U201.58 (PB6); also elsewhere on the board
N20_PWM2: U201.59 (PB7); also elsewhere on the board
N20_PWM3: U201.61 (PB8); also elsewhere on the board
N20_PWM4: U201.62 (PB9); also elsewhere on the board
SAFETY_LED: U201.40 (PC9); also elsewhere on the board
SAFETY_SW: U201.2 (PC13); also elsewhere on the board
SERVO1: U201.56 (PB4); also elsewhere on the board
SERVO2: U201.57 (PB5); also elsewhere on the board
SERVO3: U201.26 (PB0); also elsewhere on the board
SERVO4: U201.27 (PB1); also elsewhere on the board
SPI1_CS_BARO: U201.24 (PC4); also elsewhere on the board
SPI1_CS_FLASH: U201.25 (PC5); also elsewhere on the board
SPI1_CS_IMU: U201.20 (PA4); also elsewhere on the board
SPI1_MISO: U201.22 (PA6); also elsewhere on the board
SPI1_MOSI: U201.23 (PA7); also elsewhere on the board
SPI1_SCK: U201.21 (PA5); also elsewhere on the board
UART4_RX: U201.15 (PA1); also elsewhere on the board
UART4_TX: U201.14 (PA0/WKUP); also elsewhere on the board
UART5_RX: U201.54 (PD2); also elsewhere on the board
UART5_TX: U201.53 (PC12); also elsewhere on the board
USART1_RX: U201.43 (PA10); also elsewhere on the board
USART1_TX: U201.42 (PA9); also elsewhere on the board
USART2_RX: U201.17 (PA3); also elsewhere on the board
USART2_TX: U201.16 (PA2); also elsewhere on the board
USART3_RX: U201.52 (PC11); also elsewhere on the board
USART3_TX: U201.51 (PC10); also elsewhere on the board

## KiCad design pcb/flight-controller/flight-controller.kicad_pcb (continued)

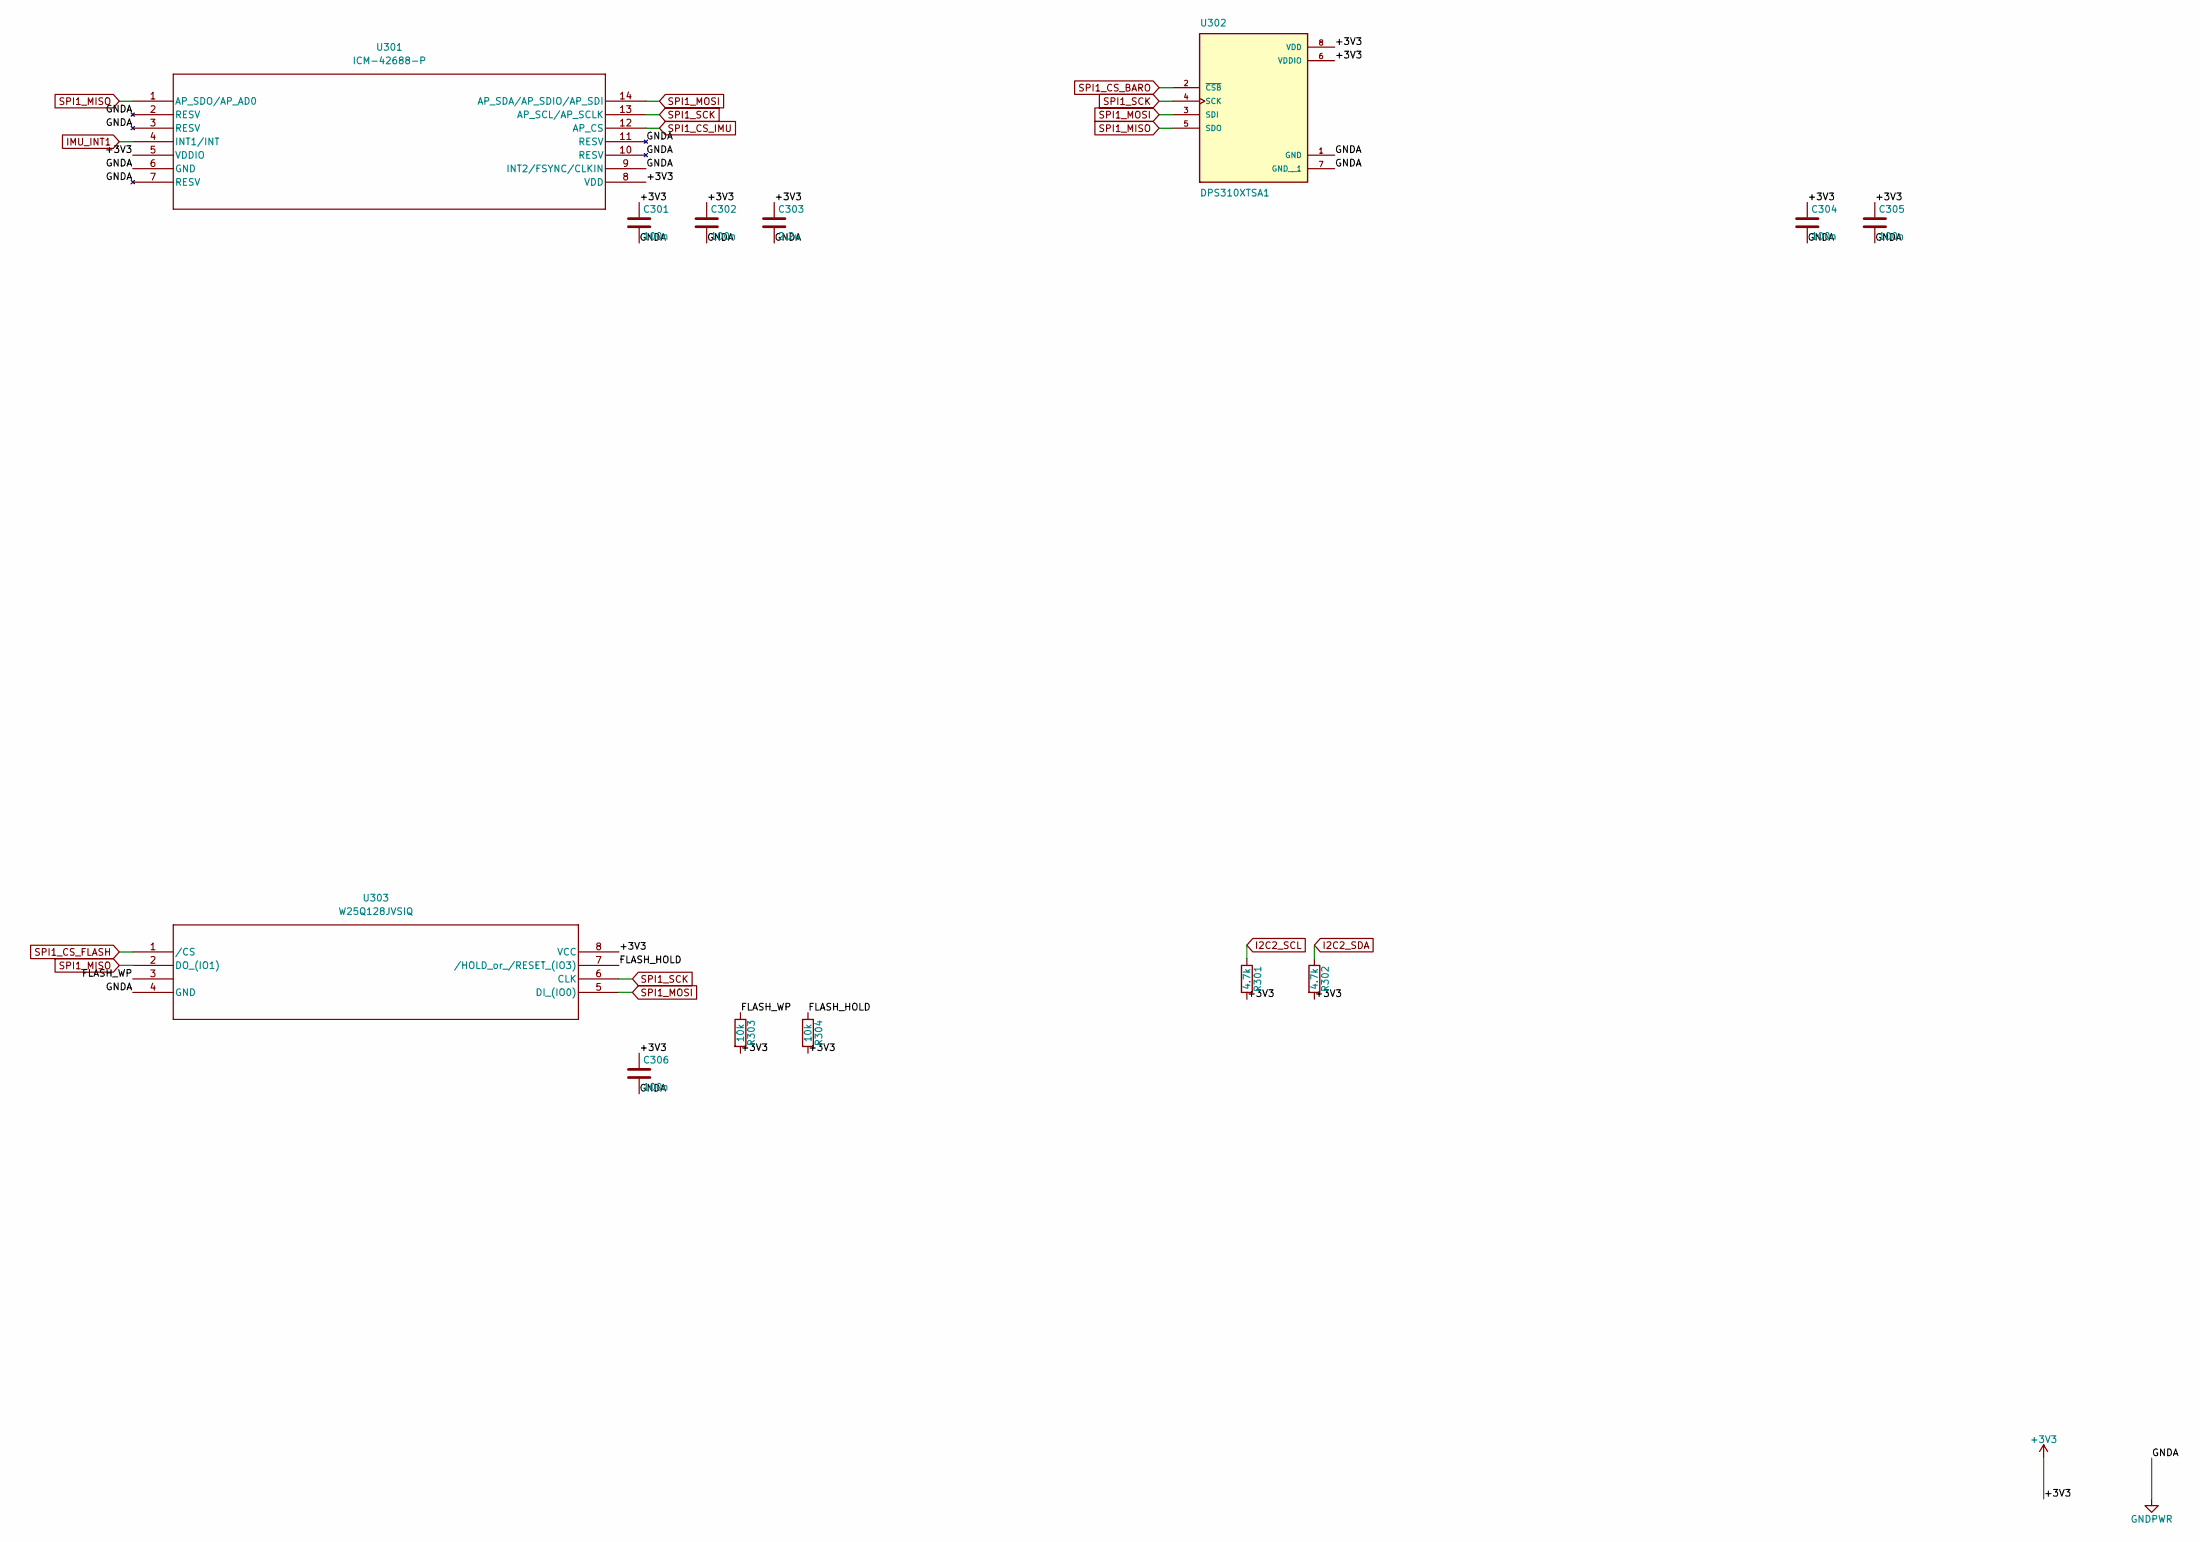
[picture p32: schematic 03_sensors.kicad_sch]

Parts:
C301, C302, C304, C305, C306: 100n; C_0402_1005Metric
C303: 2.2u; C_0603_1608Metric
R301, R302: 4.7k; R_0603_1608Metric
R303, R304: 10k; R_0402_1005Metric
U301: ICM-42688-P; LGA14_2P5X3X0P91_TDK
U302: DPS310XTSA1; XDCR_DPS310XTSA1
U303: W25Q128JVSIQ; SOIC_128JVSIQ_WIN

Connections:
/03_SENSORS/FLASH_HOLD: R304.1, U303.7 (/HOLD_or_/RESET_(IO3))
/03_SENSORS/FLASH_WP: R303.1, U303.3
I2C2_SCL: R301.1; also elsewhere on the board
I2C2_SDA: R302.1; also elsewhere on the board
IMU_INT1: U301.4 (INT1/INT); also elsewhere on the board
SPI1_CS_BARO: U302.2 (~CSB); also elsewhere on the board
SPI1_CS_FLASH: U303.1 (/CS); also elsewhere on the board
SPI1_CS_IMU: U301.12 (AP_CS); also elsewhere on the board
SPI1_MISO: U301.1 (AP_SDO/AP_AD0), U302.5 (SDO), U303.2 (DO_(IO1)); also elsewhere on the board
SPI1_MOSI: U301.14 (AP_SDA/AP_SDIO/AP_SDI), U302.3 (SDI), U303.5 (DI_(IO0)); also elsewhere on the board
SPI1_SCK: U301.13 (AP_SCL/AP_SCLK), U302.4 (SCK), U303.6 (CLK); also elsewhere on the board

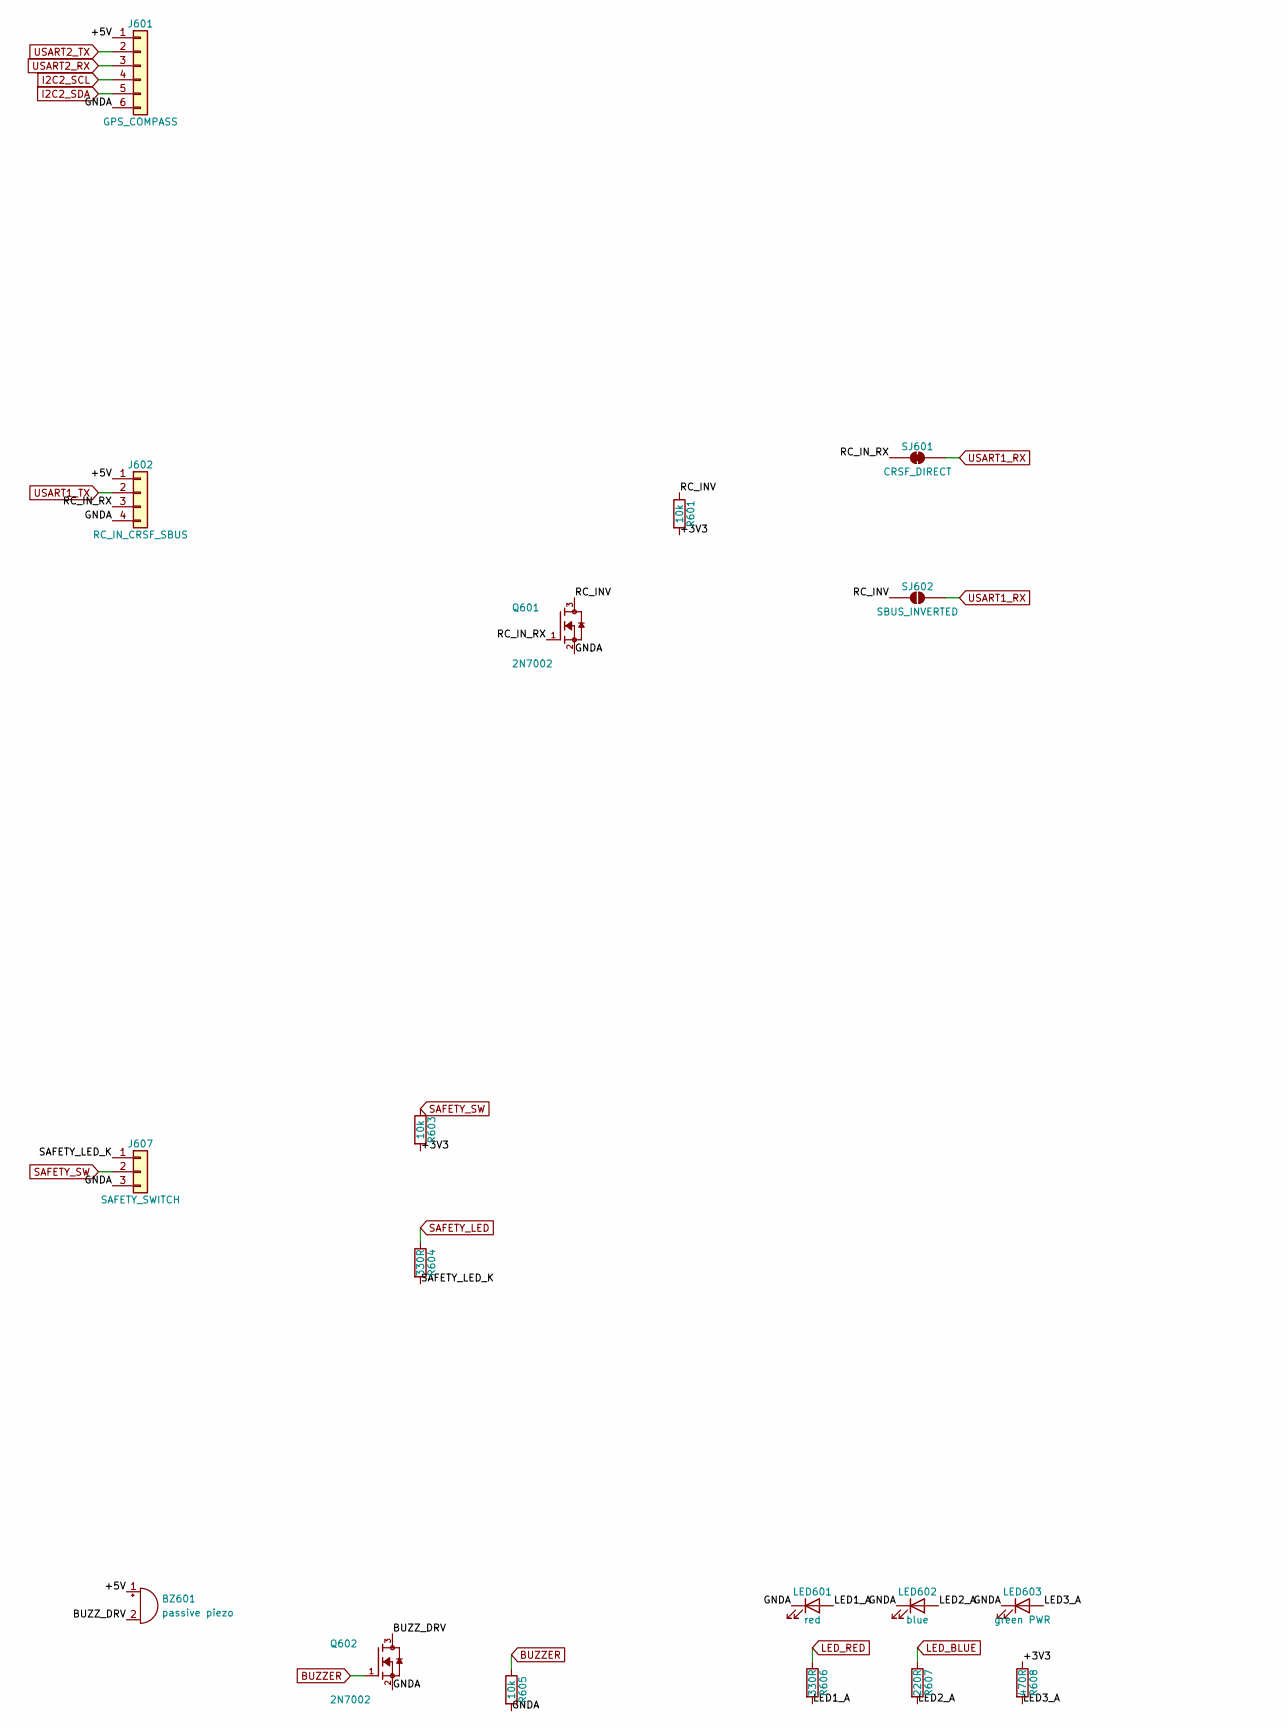
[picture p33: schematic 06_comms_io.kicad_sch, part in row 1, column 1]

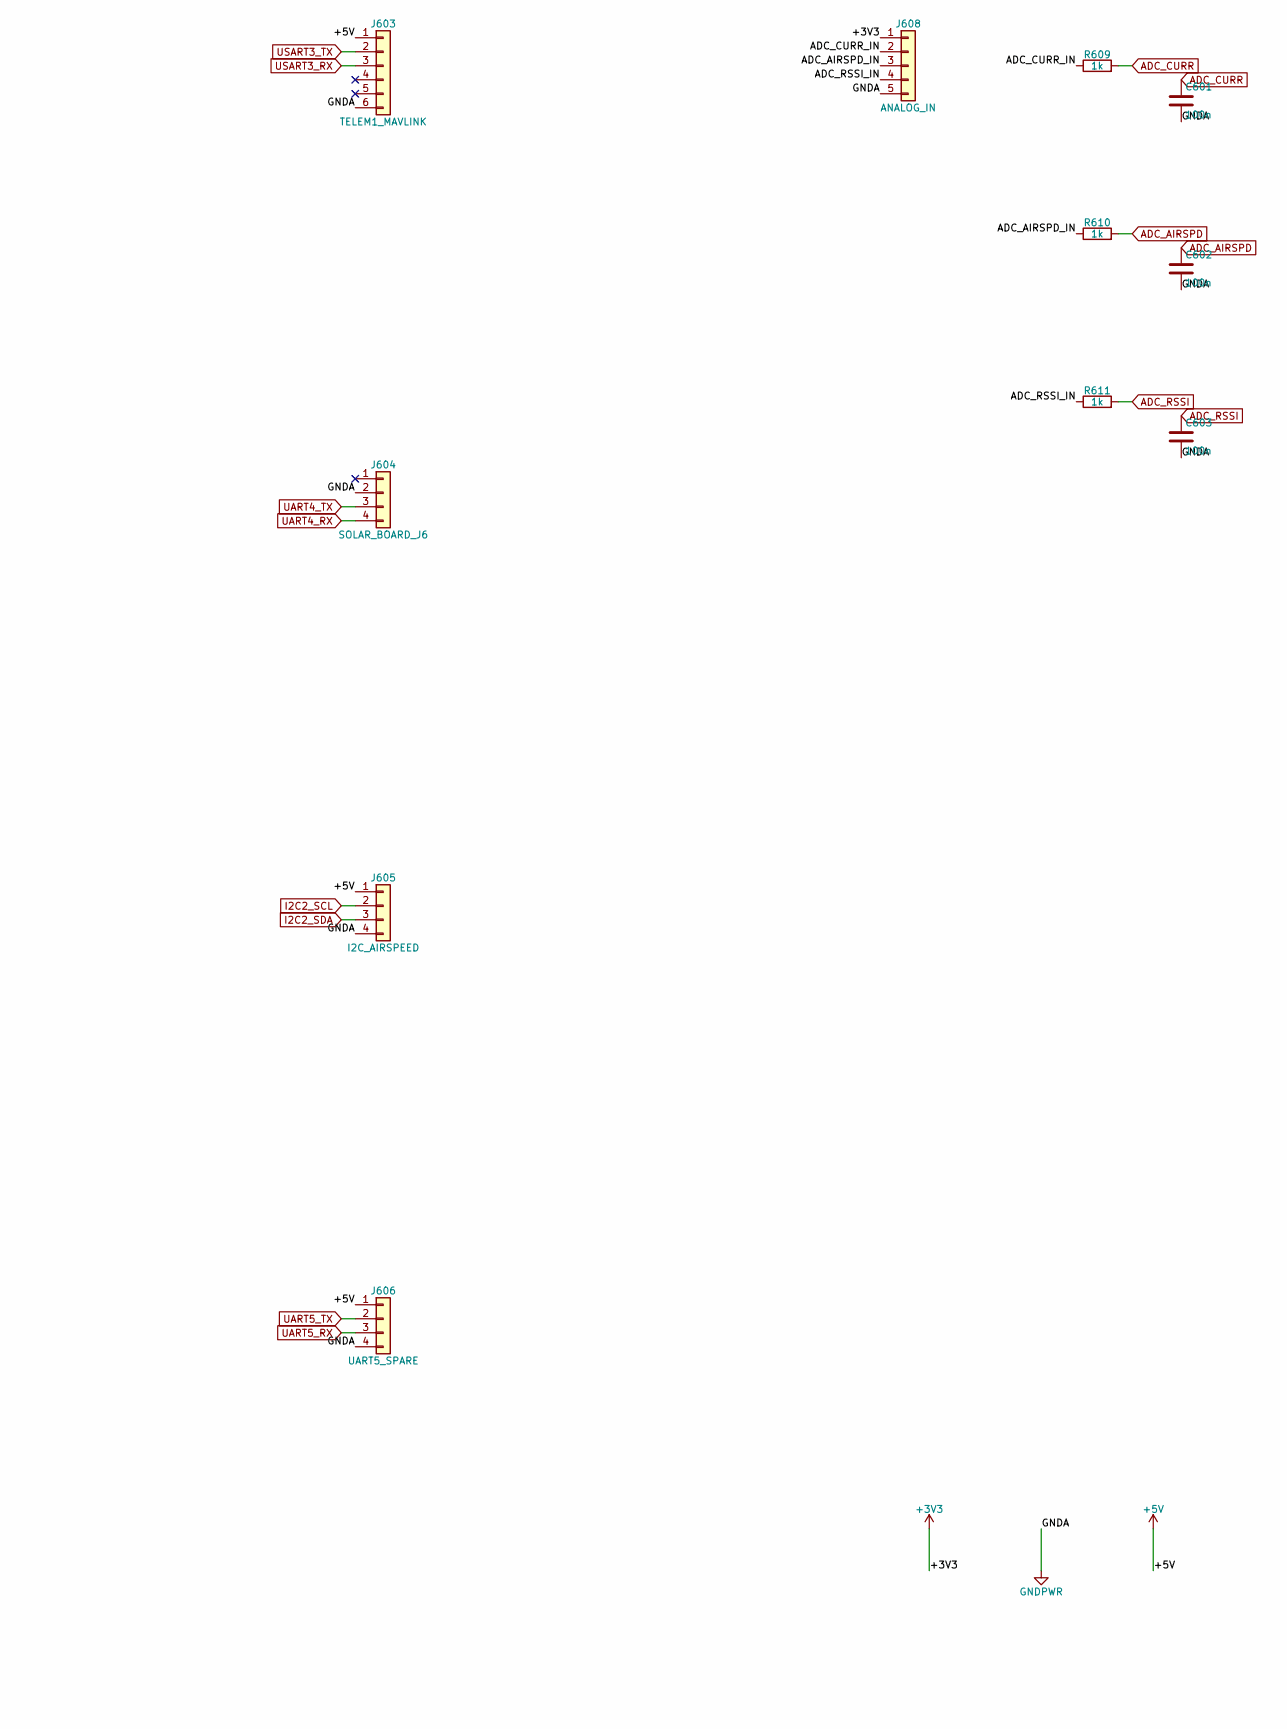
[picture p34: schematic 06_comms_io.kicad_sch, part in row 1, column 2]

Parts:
BZ601: passive piezo; Buzzer_12x9.5RM7.6
C601, C602, C603: 100n; C_0603_1608Metric
J601: GPS_COMPASS; JST_GH_BM06B-GHS-TBT_1x06-1MP_P1.25mm_Vertical
J602: RC_IN_CRSF_SBUS; JST_GH_BM04B-GHS-TBT_1x04-1MP_P1.25mm_Vertical
J603: TELEM1_MAVLINK; JST_GH_BM06B-GHS-TBT_1x06-1MP_P1.25mm_Vertical
J604: SOLAR_BOARD_J6; JST_GH_BM04B-GHS-TBT_1x04-1MP_P1.25mm_Vertical
J605: I2C_AIRSPEED; JST_GH_BM04B-GHS-TBT_1x04-1MP_P1.25mm_Vertical
J606: UART5_SPARE; JST_GH_BM04B-GHS-TBT_1x04-1MP_P1.25mm_Vertical
J607: SAFETY_SWITCH; JST_GH_BM03B-GHS-TBT_1x03-1MP_P1.25mm_Vertical
J608: ANALOG_IN; JST_GH_BM05B-GHS-TBT_1x05-1MP_P1.25mm_Vertical
LED601: red; LED_0603_1608Metric
LED602: blue; LED_0603_1608Metric
LED603: green PWR; LED_0603_1608Metric
Q601, Q602: 2N7002; TRANS_2N7002
R601, R603, R605: 10k; R_0603_1608Metric
R604, R606: 330R; R_0603_1608Metric
R607: 220R; R_0603_1608Metric
R608: 470R; R_0603_1608Metric
R609, R610, R611: 1k; R_0603_1608Metric
SJ601: CRSF_DIRECT; SolderJumper-2_P1.3mm_Bridged_Pad1.0x1.5mm
SJ602: SBUS_INVERTED; SolderJumper-2_P1.3mm_Open_Pad1.0x1.5mm

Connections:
/06_COMMS_IO/ADC_AIRSPD_IN: J608.3, R610.1
/06_COMMS_IO/ADC_CURR_IN: J608.2, R609.1
/06_COMMS_IO/ADC_RSSI_IN: J608.4, R611.1
/06_COMMS_IO/BUZZ_DRV: BZ601.2 (-), Q602.3
/06_COMMS_IO/LED1_A: LED601.2 (A), R606.2
/06_COMMS_IO/LED2_A: LED602.2 (A), R607.2
/06_COMMS_IO/LED3_A: LED603.2 (A), R608.2
/06_COMMS_IO/RC_INV: Q601.3, R601.1, SJ602.1 (A)
/06_COMMS_IO/RC_IN_RX: J602.3, Q601.1, SJ601.1 (A)
/06_COMMS_IO/SAFETY_LED_K: J607.1, R604.2
ADC_AIRSPD: C602.1, R610.2; also elsewhere on the board
ADC_CURR: C601.1, R609.2; also elsewhere on the board
ADC_RSSI: C603.1, R611.2; also elsewhere on the board
BUZZER: Q602.1, R605.1; also elsewhere on the board
I2C2_SCL: J601.4, J605.2; also elsewhere on the board
I2C2_SDA: J601.5, J605.3; also elsewhere on the board
LED_BLUE: R607.1; also elsewhere on the board
LED_RED: R606.1; also elsewhere on the board
SAFETY_LED: R604.1; also elsewhere on the board
SAFETY_SW: J607.2, R603.1; also elsewhere on the board
UART4_RX: J604.4; also elsewhere on the board
UART4_TX: J604.3; also elsewhere on the board
UART5_RX: J606.3; also elsewhere on the board
UART5_TX: J606.2; also elsewhere on the board
USART1_RX: SJ601.2 (B), SJ602.2 (B); also elsewhere on the board
USART1_TX: J602.2; also elsewhere on the board
USART2_RX: J601.3; also elsewhere on the board
USART2_TX: J601.2; also elsewhere on the board
USART3_RX: J603.3; also elsewhere on the board
USART3_TX: J603.2; also elsewhere on the board

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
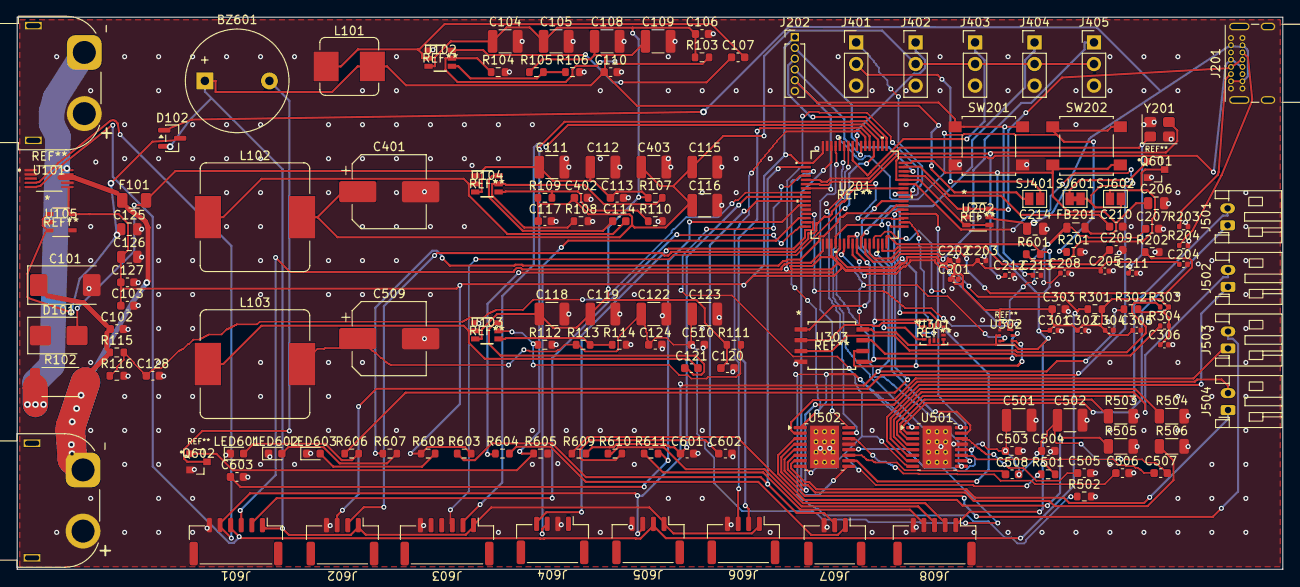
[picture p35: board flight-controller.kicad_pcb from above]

Board: 2 copper layers, 149.0 x 65.0 mm, 155 parts (0 on the bottom side), 109 nets.

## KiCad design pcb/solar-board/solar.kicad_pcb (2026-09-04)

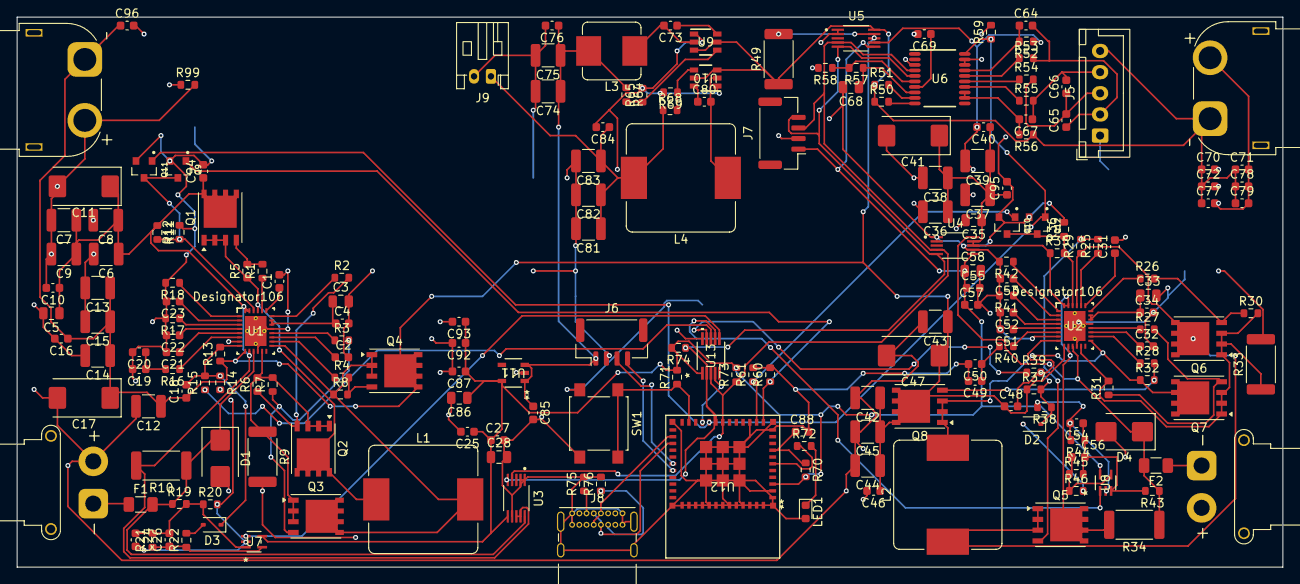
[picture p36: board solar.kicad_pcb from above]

Board: 2 copper layers, 149.6 x 65.0 mm, 201 parts (0 on the bottom side), 104 nets.

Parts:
C1, C2, C4, C10, C16, C21, C23, C24, C25, C27, C31, C32, C34, C40, C46, C51, C53, C54, C55, C57, C64, C65, C66, C67, C69, C72, C73, C76, C79, C80, C84, C87, C92, C94, C95, C96: 100n; C_0603_1608Metric
C3, C33, C86: 10u; C_0805_2012Metric
C5, C28, C35, C58, C68: 1u; C_0805_2012Metric
C6, C7, C8, C9, C12, C13, C14, C15, C36, C37, C38, C39, C42, C43, C44, C45, C74, C75, C81, C82, C83: 22u; C_1210_3225Metric
C11, C17, C41, C47: 100u_poly; CP_EIA-7343-31_Kemet-D
C18, C48: 22p; C_0603_1608Metric
C19, C49: 4.7n; C_0603_1608Metric
C20, C50: 100p; C_0603_1608Metric
C22, C52: 390p; C_0603_1608Metric
C26, C56: 22n; C_0603_1608Metric
C70, C71, C77, C78: 10u; C_0603_1608Metric
C85, C88, C93: 1u; C_0603_1608Metric
D1, D4: SMBJ45A; D_SMB
D2, D3: BAT54; D_SOD-323
F1, F2: 10A; Fuse_1206_3216Metric
J1: XT30_panelA; AMASS_XT30PW-F_1x02_P2.50mm_Horizontal
J2: XT30_panelB; AMASS_XT30PW-F_1x02_P2.50mm_Horizontal
J3: XT60_battery; AMASS_XT60PW-F_1x02_P7.20mm_Horizontal
J4: XT60_ESCout; AMASS_XT60PW-F_1x02_P7.20mm_Horizontal
J5: JST-XH_balance; JST_XH_B5B-XH-A_1x05_P2.50mm_Vertical
J6: JST-GH_toFC; JST_GH_BM04B-GHS-TBT_1x04-1MP_P1.25mm_Vertical
J7: JST-GH_I2C; JST_GH_BM04B-GHS-TBT_1x04-1MP_P1.25mm_Vertical
J8: USB_C_Receptacle_USB2.0_16P; USB_C_Receptacle_GCT_USB4085
J9: JST-PH_servo; JST_PH_S2B-PH-K_1x02_P2.00mm_Horizontal
L1, L2: 10uH SRP1245A-100M; L_Bourns_SRP1245A
L3: 10uH SRP7028A-100M; L_Bourns_SRP7028A_7.3x6.6mm
L4: 6.8uH SRP1245A-6R8M; L_Bourns_SRP1245A
LED1: green; LED_0603_1608Metric
Q1, Q2, Q3, Q4, Q5, Q6, Q7, Q8: SIR626DP; PowerPAK_SO-8_Single
Q9, Q10, Q11, Q12: Q_NMOS_GSD; TRANS_2N7002
R1, R2, R3, R4, R25, R26, R27, R28: 2.2; R_0603_1608Metric
R5, R6, R7, R8, R12, R14, R16, R20, R29, R30, R31, R32, R36, R38, R40, R44, R57, R60, R61, R65, R69, R70, R71: 10k; R_0603_1608Metric
R9, R33: 10m; R_2512_6332Metric
R10, R34: 5m; R_2512_6332Metric
R11, R35: 22.1k; R_0603_1608Metric
R13, R37: 130k; R_0603_1608Metric
R15, R39: 33k; R_0603_1608Metric
R17, R41: 84.5k; R_0603_1608Metric
R18, R42: 93.1k; R_0603_1608Metric
R19, R43: 120k; R_0603_1608Metric
R21, R45: 1M; R_0603_1608Metric
R22, R46: 4.7k; R_0603_1608Metric
R49: 1m; R_2512_6332Metric
R50, R51, R52, R53, R54, R55, R56: 100; R_0603_1608Metric
R58: 10k_NTC; R_0603_1608Metric
R59: 100k; R_0603_1608Metric
R64: 75k; R_0603_1608Metric
R68: 90.9k; R_0603_1608Metric
R72: 1k; R_0603_1608Metric
R73, R74: 2.2k; R_0603_1608Metric
R75, R76: 5.1k; R_0603_1608Metric
R99: 0R; R_0603_1608Metric
SW1: tact; SW_SPST_B3S-1000
U1, U2: LM5175RHFR; RHF0028A
U3, U4, U5: INA228AIDGSR; SOP50P490X110-10N
U6: BQ7692000PWR; PW0020A_N
U7, U8: TLV9061IDCKR; DCK5_TEX
U9: TPS54202DDCR; DDC0006A_N
U10: TPS54302DDCR; DDC0006A_N
U11: AP2112K-3.3TRG1; SOT_RG1_DIO
U12: ESP32-C3-MINI-1-N4; ESP32-C3-MINI-1_EXP
U13: MCP4728A0T-E_UN; MSOP10_MC_MCH

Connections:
/+3V3: C25.1, C27.1, C28.1, C55.1, C57.1, C58.1, C86.1, C87.1, C92.1, C93.1, J7.1, R70.2, R71.2, R73.2, R74.2, U3.6 (VS), U4.6 (VS), U5.6 (VS), U7.5 (V+), U8.5 (V+), U11.5 (VOUT), U12.3 (3V3), U13.1 (VDD)
/+5V: C74.1, C75.1, C76.1, C85.1, J6.1, L3.2, R64.1, U11.1 (VIN), U11.3 (EN)
/+6V: C81.1, C82.1, C83.1, C84.1, J9.1, L4.2, R68.1
/AGND: C19.2, C20.2, C21.2, C22.2, C23.2, C24.2, C25.2, C27.2, C28.2, C49.2, C50.2, C51.2, C52.2, C53.2, C54.2, C55.2, C57.2, C58.2, C68.2, C69.2, C85.2, C86.2, C87.2, C88.2, C92.2, C93.2, C94.2, C95.2, C96.2, J7.2, J8.A1 (GND), J8.A12 (GND), J8.B1 (GND), J8.B12 (GND), J8.SH (SHIELD), LED1.2 (A), Q9.2, Q10.2, Q11.2, Q12.2, R12.2, R14.2, R17.2, R18.2, R20.2, R36.2, R38.2, R41.2, R42.2, R44.2, R58.2, R59.2, R60.2, R61.2, R75.2, R76.2, R99.1, SW1.2, U1.7 (AGND), U2.7 (AGND), U3.1 (A1), U3.2 (A0), U3.7 (GND), U4.1 (A1), U4.2 (A0), U4.7 (GND), U5.1 (A1), U5.2 (A0), U6.3 (VSS), U6.18 (SRP), U6.19 (SRN), U7.2 (V-), U8.2 (V-), U11.2 (GND), U12.1 (GND), U12.2 (GND), U12.11 (GND), U12.14 (GND), U12.36 (GND), U12.37 (GND), U12.38 (GND), U12.39 (GND), U12.40 (GND), U12.41 (GND), U12.42 (GND), U12.43 (GND), U12.44 (GND), U12.45 (GND), U12.46 (GND), U12.47 (GND), U12.48 (GND), U12.49 (GND), U12.50 (GND), U12.51 (GND), U12.52 (GND), U12.53 (GND), U12.54 (GND), U12.55 (GND), U12.56 (GND), U12.57 (GND), U12.58 (GND), U12.59 (GND), U12.60 (GND), U12.61 (GND), U13.10 (VSS)
/BMS_ALERT: Q11.1, Q12.1, R59.1, U6.20 (ALERT), U12.20 (IO6)
/BOOT1_A: C1.1, U1.23 (BOOT1)
/BOOT1_B: C31.1, U2.23 (BOOT1)
/BOOT2_A: C2.1, U1.17 (BOOT2)
/BOOT2_B: C32.1, U2.17 (BOOT2)
/BOOT_5V: C73.1, U9.6 (BOOT)
/BOOT_6V: C80.1, U10.6 (BOOT)
/BOOT_BTN: R71.1, SW1.1, U12.23 (IO9)
/BQ_BAT: R50.2, U6.10 (BAT)
/BQ_CAP1: C69.1, U6.7 (CAP1)
/BQ_REGOUT: C68.1, R57.1, U6.8 (REGOUT)
/BQ_REGSRC: R51.2, U6.9 (REGSRC)
/BQ_TS1: R57.2, R58.1, U6.6 (TS1)
/CELL1: C64.2, C65.1, J5.2, R53.2
/CELL2: C65.2, C66.1, J5.3, R54.2
/CELL3: C66.2, C67.1, J5.4, R55.2
/CMPM_A: C19.1, C20.1, R16.2
/CMPM_B: C49.1, C50.1, R40.2
/COMP_A: R16.1, U1.6 (COMP)
/COMP_B: R40.1, U2.6 (COMP)
/CSP_A: Q2.1 (S), Q2.2 (S), Q2.3 (S), Q3.1 (S), Q3.2 (S), Q3.3 (S), R6.2, R7.2, R9.1, U1.13 (CS)
/CSP_B: Q6.1 (S), Q6.2 (S), Q6.3 (S), Q7.1 (S), Q7.2 (S), Q7.3 (S), R30.2, R31.2, R33.1, U2.13 (CS)
/DAC_CV_A: R15.1, U13.8 (VOUTC)
/DAC_CV_B: R39.1, U13.9 (VOUTD)
/DAC_LDAC: U12.21 (IO7), U13.4 (*LDAC)
/DAC_MPPT_A: U7.1 (IN+), U13.6 (VOUTA)
/DAC_MPPT_B: U8.1 (IN+), U13.7 (VOUTB)
/DITH_A: C23.1, U1.2 (DITH)
/DITH_B: C53.1, U2.2 (DITH)
/EN_A: Q9.3, Q11.3, R11.2, R12.1, U1.26 (EN_UVLO)
/EN_A_CTL: Q9.1, R60.1, U12.12 (IO0)
/EN_B: Q10.3, Q12.3, R35.2, R36.1, U2.26 (EN_UVLO)
/EN_B_CTL: Q10.1, R61.1, U12.13 (IO1)
/FB_5V: R64.2, R65.1, U9.4 (FB)
/FB_6V: R68.2, R69.1, U10.4 (FB)
/FB_A: C18.2, D3.1 (K), R13.2, R14.1, R15.2, U1.8 (FB)
/FB_B: C48.2, D2.1 (K), R37.2, R38.1, R39.2, U2.8 (FB)
/FC_RX: J6.3, U12.30 (RXD0)
/FC_TX: J6.4, U12.31 (TXD0)
/G1_A: Q1.4 (G), R1.2, R5.2
/G1_B: Q5.4 (G), R25.2, R29.2
/G2_A: Q2.4 (G), R2.2, R6.1
/G2_B: Q6.4 (G), R26.2, R30.1
/G3_A: Q3.4 (G), R3.2, R7.1
/G3_B: Q7.4 (G), R27.2, R31.1
/G4_A: Q4.4 (G), R4.2, R8.2
/G4_B: Q8.4 (G), R28.2, R32.2
/HDRV1_A: R1.1, U1.24 (HDRV1)
/HDRV1_B: R25.1, U2.24 (HDRV1)
/HDRV2_A: R4.1, U1.16 (HDRV2)
/HDRV2_B: R28.1, U2.16 (HDRV2)
/INJ_A: D3.2 (A), R22.2
/INJ_B: D2.2 (A), R46.2
/LDRV1_A: R2.1, U1.22 (LDRV1)
/LDRV1_B: R26.1, U2.22 (LDRV1)
/LDRV2_A: R3.1, U1.18 (LDRV2)
/LDRV2_B: R27.1, U2.18 (LDRV2)
/LED_A: LED1.1 (K), R72.2
/LED_DRV: R72.1, U12.6 (IO3)
/MCU_EN: C88.1, R70.1, U12.8 (EN)
/MODE_A: R18.1, U1.1 (MODE)
/MODE_B: R42.1, U2.1 (MODE)
/OPA_A: C26.1, R21.1, R22.1, U7.4 (OUT)
/OPA_B: C56.1, R45.1, R46.1, U8.4 (OUT)
/PACK_P: C70.1, C71.1, C72.1, C77.1, C78.1, C79.1, J3.1, J5.5, R49.1, R50.1, R51.1, R56.1, U5.10 (IN+), U9.3 (VIN), U9.5 (EN), U10.3 (VIN), U10.5 (EN)
/PGND: C1.2, C2.2, C3.2, C4.2, C5.2, C6.2, C7.2, C8.2, C9.2, C10.2, C11.2, C12.2, C13.2, C14.2, C15.2, C16.2, C17.2, C31.2, C32.2, C33.2, C34.2, C35.2, C36.2, C37.2, C38.2, C39.2, C40.2, C41.2, C42.2, C43.2, C44.2, C45.2, C46.2, C47.2, C70.2, C71.2, C72.2, C74.2, C75.2, C76.2, C77.2, C78.2, C79.2, C81.2, C82.2, C83.2, C84.2, D1.2 (A2), D4.2 (A2), J1.2, J2.2, J3.2, J4.2, J5.1, J6.2, J9.2, R9.2, R33.2, R52.1, R65.2, R69.2, R99.2, U1.12 (CSG), U1.19 (PGND), U1.29 (PAD), U2.12 (CSG), U2.19 (PGND), U2.29 (PAD), U5.7 (GND), U9.1 (GND), U10.1 (GND)
/RT_A: R17.1, U1.3 (RT)
/RT_B: R41.1, U2.3 (RT)
/SCL: J7.4, R74.1, U3.5 (SCL), U4.5 (SCL), U5.5 (SCL), U6.5 (SCL), U12.19 (IO5), U13.2 (SCL)
/SDA: J7.3, R73.1, U3.4 (SDA), U4.4 (SDA), U5.4 (SDA), U6.4 (SDA), U12.18 (IO4), U13.3 (SDA)
/SLOPE_A: C22.1, U1.4 (SLOPE)
/SLOPE_B: C52.1, U2.4 (SLOPE)
/SOL_A_IN: F1.1, J1.1
/SOL_A_P: D1.1 (A1), F1.2, R10.1, R19.1, U1.11 (ISNS+), U3.10 (IN+)
/SOL_B_IN: F2.1, J2.1
/SOL_B_P: D4.1 (A1), F2.2, R34.1, R43.1, U2.11 (ISNS+), U4.10 (IN+)
/SS_A: C21.1, U1.5 (SS)
/SS_B: C51.1, U2.5 (SS)
/SW1_A: L1.1, Q1.1 (S), Q1.2 (S), Q1.3 (S), Q2.5 (D), R5.1, U1.25 (SW1)
/SW1_B: L2.1, Q5.1 (S), Q5.2 (S), Q5.3 (S), Q6.5 (D), R29.1, U2.25 (SW1)
/SW2_A: L1.2, Q3.5 (D), Q4.1 (S), Q4.2 (S), Q4.3 (S), R8.1, U1.15 (SW2)
/SW2_B: L2.2, Q7.5 (D), Q8.1 (S), Q8.2 (S), Q8.3 (S), R32.1, U2.15 (SW2)
/SW_5V: C73.2, L3.1, U9.2 (SW)
/SW_6V: C80.2, L4.1, U10.2 (SW)
/USB_CC1: J8.A5 (CC1), R75.1
/USB_CC2: J8.B5 (CC2), R76.1
/USB_DM: J8.A7 (D-), J8.B7 (D-), U12.26 (IO18)
/USB_DP: J8.A6 (D+), J8.B6 (D+), U12.27 (IO19)
/VC0: C64.1, R52.2, U6.17 (VC0)
/VC1: R53.1, U6.16 (VC1)
/VC2: R54.1, U6.15 (VC2)
/VC3: R55.1, U6.14 (VC3)
/VC4: C67.2, R56.2, U6.12 (VC5), U6.13 (VC4)
/VCC_A: C3.1, C4.1, U1.20 (VCC), U1.21 (BIAS)
/VCC_B: C33.1, C34.1, U2.20 (VCC), U2.21 (BIAS)
/VIN_A: C5.1, C6.1, C7.1, C8.1, C9.1, C10.1, C11.1, C94.1, Q1.5 (D), R10.2, R11.1, U1.10 (ISNS-), U1.27 (VIN), U1.28 (VINSNS), U3.8 (VBUS), U3.9 (IN-)
/VIN_B: C35.1, C36.1, C37.1, C38.1, C39.1, C40.1, C41.1, C95.1, Q5.5 (D), R34.2, R35.1, U2.10 (ISNS-), U2.27 (VIN), U2.28 (VINSNS), U4.8 (VBUS), U4.9 (IN-)
/VPACK: C12.1, C13.1, C14.1, C15.1, C16.1, C17.1, C18.1, C42.1, C43.1, C44.1, C45.1, C46.1, C47.1, C48.1, C96.1, J4.1, Q4.5 (D), Q8.5 (D), R13.1, R37.1, R49.2, U1.9 (VOSNS), U2.9 (VOSNS), U5.8 (VBUS), U5.9 (IN-)
/VPAN_A: C24.1, C26.2, R19.2, R20.1, R21.2, U7.3 (IN-)
/VPAN_B: C54.1, C56.2, R43.2, R44.1, R45.2, U8.3 (IN-)

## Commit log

2026-08-25 nppt board thing schematic yeah
    [flight-controller.kicad_pcb, flight-controller.kicad_sch, solar.kicad_pcb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]
2026-09-01 flight controller
    [01_power.kicad_sch, 02_mcu.kicad_sch, 03_sensors.kicad_sch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]
2026-09-01 Expand README with assembly instructions and PCB details
    Added assembly instructions for the plane and PCB details.
2026-09-08 change connector directions
    [flight-controller.kicad_pcb]
2026-09-10 add pcb pics
2026-09-10 Add BOM to readme
2026-09-10 Update README with CAD design link
    Added a link to the CAD design document for reference.
